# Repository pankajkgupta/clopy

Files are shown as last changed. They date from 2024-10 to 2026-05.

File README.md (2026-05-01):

# CLoPy
Closed-loop feedback training system (CLoPy) for neurofeedback and specified movement feedback in mice

This work accompanies the research paper - 
https://www.biorxiv.org/content/10.1101/2024.11.02.619716v1

For more documentation please see the Docs: https://clopy-docs.readthedocs.io/

## Folder structure
```
clopy/
│
├── 📁 analysis/                           Data analysis and visualization
│   ├── get_clmf_data.py                  Load and process CLMF behavioral data
│   ├── plot_clmf.py                      Generate CLMF figures and plots
│   └── plot_clnf.py                      Generate CLNF figures and plots
│
├── 📁 behavior/                           CLMF (Movement Feedback) Experiments
│   └── cla_dlc_trials_speed.py           Main CLMF experiment script
│
├── 📁 brain/                              CLNF (Neurofeedback) Experiments
│   ├── cla_reward_punish_1roi.py         CLNF single ROI experiment
│   └── cla_reward_punish_2roi.py         CLNF dual ROI experiment
│
├── 📁 3D-print/                           3D-printable hardware components
│   ├── MirrorHolderFront.dxf
│   ├── MirrorHolderRear.dxf
│   ├── MouseEnclosureTop.dxf
│   ├── MouseHeadFixBack.dxf
│   ├── MouseHeadFixBottom.dxf
│   ├── MouseHeadFixPost.dxf
│   └── MouseHeadFixTop.dxf
│
├── 📁 processed_data/                     Preprocessed data for figure reproduction
│   ├── clmf_kld_df.csv
│   ├── clmf_sessions_df.csv
│   ├── clmf_trials_df.csv
│   └── clnf_sessions_df.csv
│
├── 📁 docs/                               ReadTheDocs documentation
│   ├── 📁 assets/                        Images, animations, and documentation
│   │   ├── fig1.png                      System overview diagram
│   │   ├── fig2.png                      Module architecture diagram
│   │   ├── animation1_clnf.gif            Neurofeedback trial example
│   │   └── *.pdf                         Hardware assembly instructions
│   │
│   ├── mkdocs.yml                        Documentation configuration
│   ├── index.md                          Home page
│   ├── installation.md                   Installation guide
│   ├── quickstart.md                     Quick start tutorial
│   ├── clnf.md                           CLNF experiment guide
│   ├── clmf.md                           CLMF experiment guide
│   ├── configuration.md                  Configuration reference
│   ├── hardware.md                       Hardware setup guide
│   ├── analysis.md                       Data analysis guide
│   ├── troubleshooting.md                Troubleshooting & FAQ
│   ├── api.md                            API reference
│   └── requirements.txt                  Documentation dependencies
│
├── 📄 CameraFactory.py                    Camera abstraction layer
├── 📄 config.ini                          Configuration file for all experiments
├── 📄 helper.py                           Utility functions and enums
├── 📄 roi_manager.py                      ROI definition and management
├── 📄 PiCameraStream.py                   Raspberry Pi camera driver
├── 📄 SentechCameraStream.py              Sentech USB camera driver
├── 📄 VideoStream.py                      Generic video stream interface
├── 📄 README.md                           Project overview
├── 📄 .readthedocs.yaml                   ReadTheDocs configuration
└── 📄 .gitignore                          Git ignore rules
```

## Setup

Overview of CLNF process (A) and CLMF process (B)

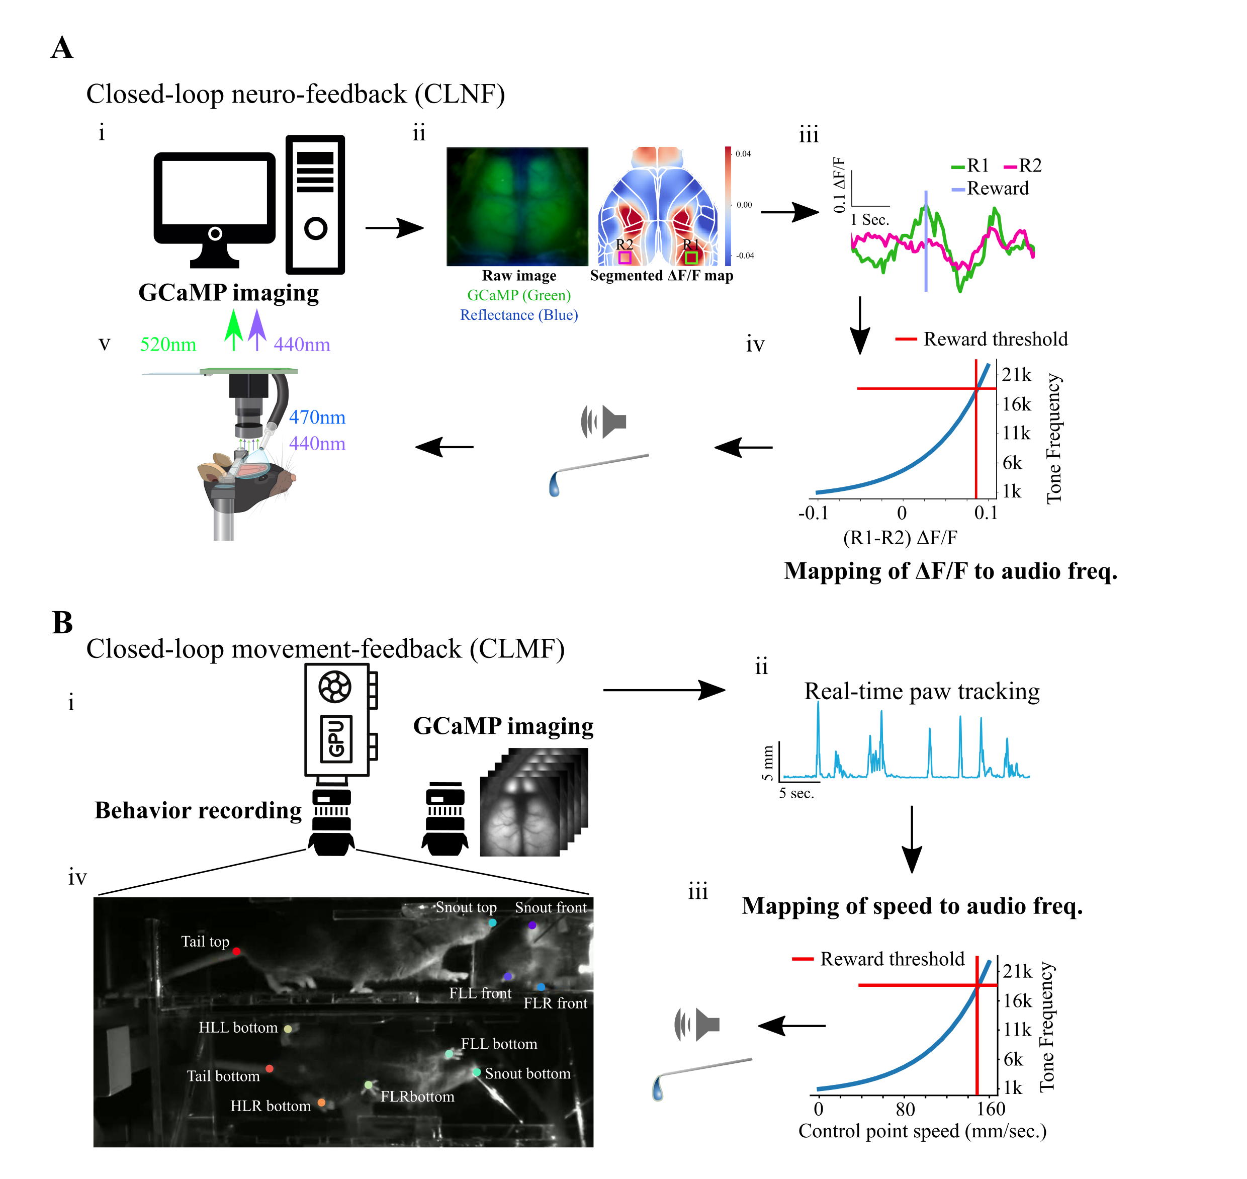
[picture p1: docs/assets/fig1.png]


## Overall modules in the system:

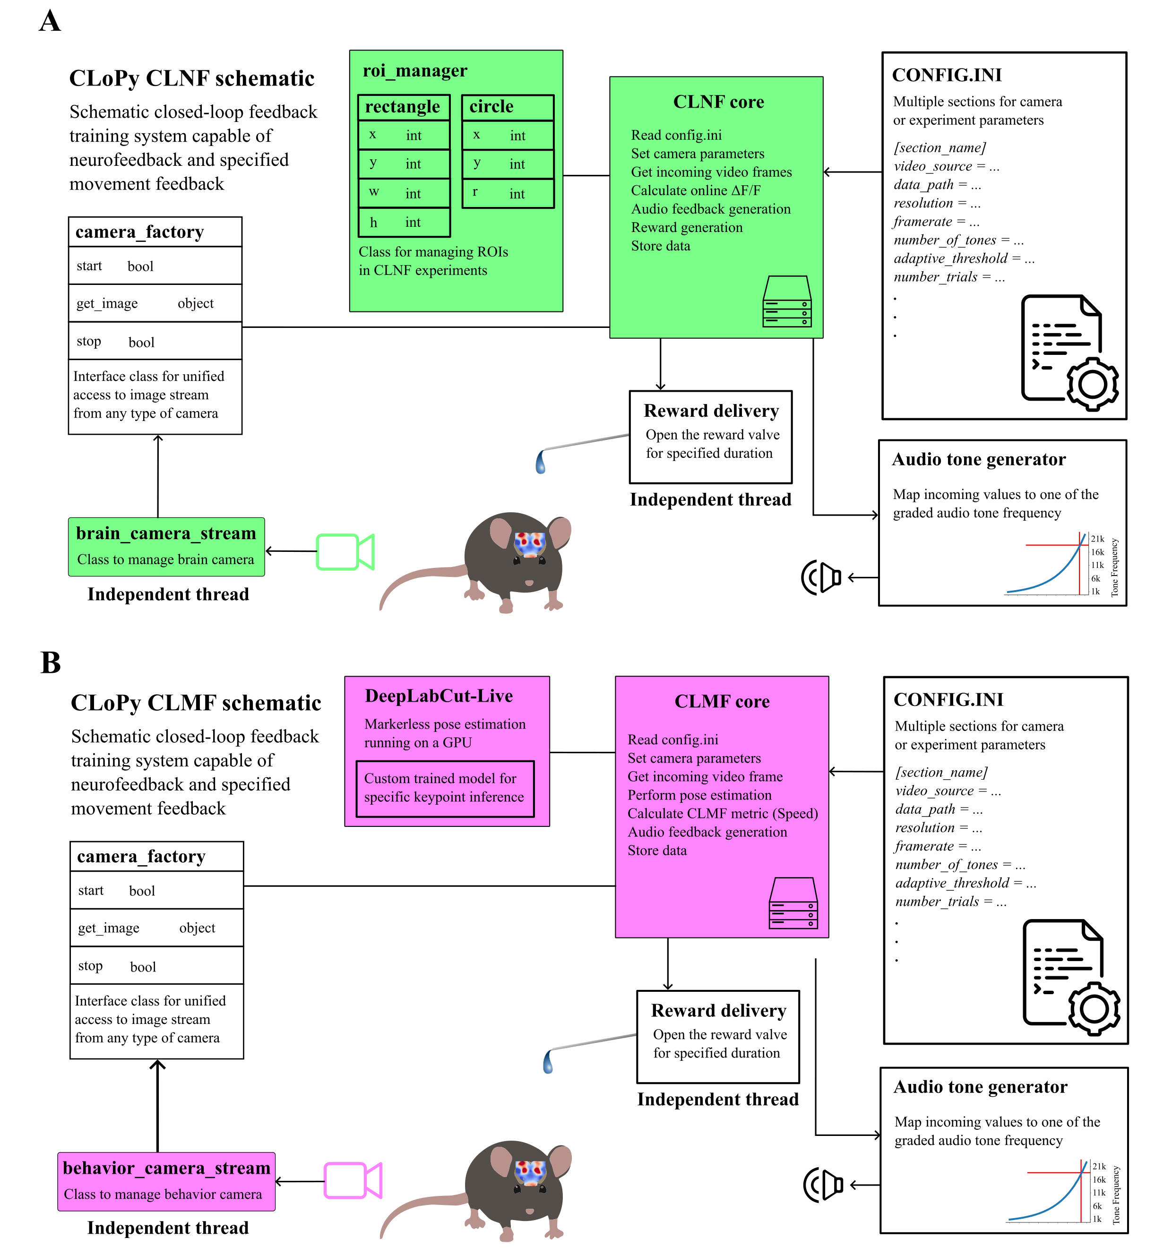
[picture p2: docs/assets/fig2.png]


## CLNF setup

> [!NOTE]
> CLNF was implemented on Raspberry Pi 4B+ and the steps below are to replicate that. 
> But the system can be adapted to other platforms with minor adaptations.

The rig hardware parts list can be found here- [CLNF_Parts_List_and_Assembly_Instructions_Gupta_et_al.pdf](https://github.com/pankajkgupta/clopy/blob/main/docs/assets/CLNF_Parts_List_and_Assembly_Instructions_Gupta_et_al.pdf)

How-to
---------------------------

Install Python >= 3.8 ([anaconda](https://docs.anaconda.com/anaconda/install/) or [miniconda](https://docs.anaconda.com/miniconda/miniconda-install/) recommended)

> [!TIP]
> We highly recommend creating a virtual environment such as using conda and installing all the Python packages in that environment

The following commands are to be run in a Terminal (Linux/MacOS)

```
conda create -n clopy
```
### Activate the conda environment

```
conda activate clopy
```

### Install dependencies
```
pip3 install opencv-python tables cvui roipoly scipy pandas joblib pillow videofig imutils gpiozero Adafruit-Blinka adafruit-circuitpython-mpr121
```

### Install [PyAudio](https://people.csail.mit.edu/hubert/pyaudio/)
Follow your platform-specific instructions. The commands below are specific to Linux-based systems

```
sudo apt-get install portaudio19-dev python3-pyaudio
```
```
pip3 install PyAudio
```

### Install [Audiostream](https://github.com/kivy/audiostream)

```
sudo apt-get install libsdl1.2-dev
```
```
sudo apt-get install libsdl-mixer1.2-dev
```
```
pip3 install cython==0.29.21
```
```
pip3 install kivy
```

### Clone the Audiostream repo:
```
git clone https://github.com/kivy/audiostream.git
```
or download as a zip and extract.

### Change the directory to the downloaded repository

```
cd audiostream
```
### Run Audiostream setup installation
```
python setup.py install
```

### After setup completes successfully, change the current directory to a directory where you want to clone CLoPy (eg. home directory)
```
cd ~
```

### Clone the CLoPy repository:

```bash
git clone https://github.com/pankajkgupta/clopy.git
```

   or download as a zip and extract.

```
cd clopy
```

### In the clopy root directory run

For CLNF experiment involving single ROI (1ROI):
```bash
python brain/cla_reward_punish_1roi.py
```
For CLNF experiment involving dual ROI (2ROI):
```bash
python brain/cla_reward_punish_2roi.py
```

... you would be prompted to enter a 'mouse_id'. After this step, you will see a 
preview window where you can make sure all settings and setup look fine 
before hitting <kbd>Esc</kbd> button the the keyboard to start a session.

If you want to interrupt the session after it starts, press the <kbd>Esc</kbd> button while the window is selected, to close the session as the program.

### Here are some reward-centered dorsal cortical maps averaged over trials of a session:

CLoPy

## CLMF setup

> [!NOTE]
> CLMF was implemented on Nvidia-Jetson Orin and steps below are to replicate that. 
> But the system can be adapted to other platforms with a GPU capable of inference.

The rig hardware parts list can be found here- [CLMF_Parts_List_and_Assembly_Instructions_Gupta_et_al.pdf](https://github.com/pankajkgupta/clopy/blob/main/docs/assets/CLMF_Parts_List_and_Assembly_Instructions_Gupta_et_al.pdf)

How-to
---------------------------

Install Python >= 3.8 ([anaconda](https://docs.anaconda.com/anaconda/install/) or [miniconda](https://docs.anaconda.com/miniconda/miniconda-install/) recommended)

> [!TIP]
> We highly recommend creating a virtual environment such as using conda and installing all the Python packages in that environment

```
conda create -n clopy
```
### Activate the conda environment

```
conda activate clopy
```

### Install dependencies
```
pip3 install opencv-python tables cvui roipoly scipy pandas joblib pillow videofig imutils
```
### Install [PyAudio](https://people.csail.mit.edu/hubert/pyaudio/)
Follow your platform-specific instructions. The commands below are specific to Linux-based systems

```
sudo apt-get install portaudio19-dev python3-pyaudio
```
```
pip3 install PyAudio
```

### Install [Audiostream](https://github.com/kivy/audiostream)

```
sudo apt-get install libsdl1.2-dev
```
```
sudo apt-get install libsdl-mixer1.2-dev
```
```
pip3 install cython==0.29.21
```
```
pip3 install kivy
```

### Clone the Audiostream repo:
```
git clone https://github.com/kivy/audiostream.git
```
or download as zip and extract.

### Change the directory to the downloaded repository

```
cd audiostream
```
### Run Audiostream setup installation
```
python setup.py install
```

### Install DeepLabCut-Live
> [!IMPORTANT]
> Please check the DeepLabCut-Live ([Kane et al, eLife 2020](https://elifesciences.org/articles/61909)) [GitHub page](https://github.com/DeepLabCut/DeepLabCut-live) for latest instructions for installing this package. 
> Please also check the tensorflow version requirements on their GitHub page. 
> 
> If all dependencies are fine, the command below usually works fine

```
pip install deeplabcut-live
```

### After setup completes successfully, change the current directory to a directory where you want to clone CLoPy (eg. home directory)
```
cd ~
```

### Clone the CLoPy repository:

```bash
git clone https://github.com/pankajkgupta/clopy.git
```

   or download as zip and extract.

```
cd clopy
```

### In the clopy root directory run

```bash
python behavior/cla_dlc_trials_speed.py
```

... you would be prompted to enter a 'mouse_id'. After this step, you will see a 
preview window where you can make sure all settings and setup look fine 
before hitting <kbd>Esc</kbd> button the the keyboard to start a session.

If you want to interrupt the session after it starts, press the <kbd>Esc</kbd> button while the window is selected, to close the session as the program.

### Here are two example trials from the CLMF experiment where the task was to move the left fore-limb (top animation)

CLoPy

### ... and later the same mouse was trained to move the right fore-limb

CLoPy

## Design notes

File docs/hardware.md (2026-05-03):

# Hardware Setup

Detailed hardware assembly instructions for CLoPy experiments.

!!! info "Parts List"
    Complete parts lists are available in the PDF: [CLNF_Parts_List_and_Assembly_Instructions_Gupta_et_al.pdf](https://github.com/pankajkgupta/clopy/blob/main/assets/CLNF_Parts_List_and_Assembly_Instructions_Gupta_et_al.pdf)

## CLNF Hardware (Raspberry Pi)

### Components

| Component | Quantity | Notes |
|---|---|---|
| Raspberry Pi 4B+ | 1 | |
| Raspberry Pi Camera v2 | 1 | |
| MPR121 Capacitive Touch | 1 | Lick detection |
| LEDs (various) | 4 | Behavior, Reward, Fail, TTL |
| Water valve | 1 | Reward delivery |
| Speaker | 1 | Audio feedback |
| Power supply | 1 | 5V 3A minimum |

### Pin Connections

#### GPIO Pinout (Board numbering)

```
┌─────────────────────────────────────────────┐
│              Raspberry Pi GPIO              │
├─────────────────────────────────────────────┤
│                                             │
│  3.3V  ──── VCC (MPR121)                    │
│  GND   ──── GND (MPR121, LEDs)              │
│  SCL   ──── SCL (MPR121)                    │
│  SDA   ──── SDA (MPR121)                    │
│                                             │
│  GPIO17 ──── Behavior LED (pin 1)           │
│  GPIO27 ──── Reward LED (pin 1)             │
│  GPIO12 ──── Fail LED (pin 1)               │
│  GPIO21 ──── Light TTL (pin 1)              │
│                                             │
└─────────────────────────────────────────────┘
```

#### LED Wiring

```
GPIO ──── Resistor (330Ω) ──── LED ──── GND
```

#### Water Valve

Connect to relay controlled by Arduino or GPIO.

### Camera Setup

1. Connect camera to CSI port
2. Enable camera in `raspi-config`:
   ```bash
   sudo raspi-config
   ```
   → Interface Options → Camera → Enable

3. Test camera:
   ```bash
   raspistill -o test.jpg
   ```

### I2C Setup for MPR121

1. Enable I2C:
   ```bash
   sudo raspi-config
   ```
   → Interface Options → I2C → Enable

2. Install tools:
   ```bash
   sudo apt-get install i2c-tools
   ```

3. Verify connection:
   ```bash
   sudo i2cdetect -y 1
   ```
   Should show device at address `0x5a`

## CLMF Hardware (Jetson Orin)

### Components

| Component | Quantity | Notes |
|---|---|---|
| Nvidia Jetson Orin | 1 | |
| Sentech Camera | 1 | USB3 preferred |
| Arduino Uno/Mega | 1 | TTL and LED control |
| Water valve | 1 | Reward delivery |
| Speaker | 1 | Audio feedback |

### Arduino Connections

#### Pinout

```
┌─────────────────────────────────────────────┐
│                 Arduino                     │
├─────────────────────────────────────────────┤
│                                             │
│  13  ──── Brain TTL (output)                │
│  7   ──── Reward LED                        │
│  12  ──── Fail LED                          │
│  40  ──── Light TTL                         │
│                                             │
│  GND  ──── GND (LEDs, TTL)                  │
│                                             │
│  Serial: /dev/ttyACM0                       │
│                                             │
└─────────────────────────────────────────────┘
```

#### Python Serial Configuration

```python
board = Arduino("115200", port="/dev/ttyACM0")
```

!!! note "Serial Port"
    The serial port may vary. Check with:
    ```bash
    ls /dev/ttyACM*
    ```

### Camera Setup (Sentech)

1. Connect via USB3
2. Verify:
   ```bash
   v4l2-ctl --list-devices
   ```

3. Test capture:
   ```bash
   gst-launch-1.0 v4l2src ! videoconvert ! ximagesink
   ```

### GPIO (Jetson)

Using RPi.GPIO library for compatibility:

```python
import RPi.GPIO as GPIO

GPIO.setmode(GPIO.BOARD)
GPIO.setup(pin, GPIO.OUT, initial=GPIO.LOW)
```

## Optical Setup

### Microscopy Configuration

```
                    ┌──────────────┐
                    │   LED Array  │
                    │  (470nm for  │
                    │   GCaMP6f)   │
                    └──────┬───────┘
                           │
                           ▼
              ┌────────────────────────┐
              │    Filter Set          │
              │  (Excitation/Emission) │
              └───────────┬────────────┘
                          │
                          ▼
              ┌────────────────────────┐
              │    Camera              │
              │  (Pi Camera / Sentech) │
              └────────────────────────┘
```

### Illumination

- **CLNF**: 470nm LED for GCaMP6f excitation
- Use appropriate filter sets for fluorescence imaging

### Calibration

1. **ppmm (Pixels per mm)**:
   - Image a ruler at your optical magnification
   - Count pixels across known distance
   - Set in config: `ppmm = <count>`

2. **Bregma Location**:
   - Image the skull landmarks
   - Note the (row, col) coordinates
   - Set in config: `bregma = <row>, <col>`

## Mouse Headfixing

### Setup

1. Headfix the mouse using the 3D-printed parts:
   - `MouseHeadFixTop.dxf`
   - `MouseHeadFixBottom.dxf`
   - `MouseHeadFixPost.dxf`

2. Position under camera with:
   - Cortex visible
   - Bregma identifiable
   - Target region in field of view

### ROI Placement

1. During preview, drag ROIs to:
   - Target brain region
   - Reference region (for dual ROI)

2. Positions are saved to `config.ini` after preview

## Audio Setup

### Speaker Requirements

- Frequency response: 1-24 kHz
- Small form factor for setup near mouse

### Audiostream Configuration

```python
from audiostream import get_output
from audiostream.sources.wave import SineSource

austream = get_output(channels=1, rate=44100, buffersize=128)
sinsource = SineSource(austream, 1000)
sinsource.start()
```

## Power Considerations

### Raspberry Pi

- Recommended: 5V 3A power supply
- Can power LEDs directly (with resistors)
- Water valve may need external power

### Jetson Orin

- Use official power supply
- Ensure adequate cooling
- Monitor power consumption for GPU work

## Safety Notes

!!! warning
- Always use appropriate resistors for LEDs
- Verify polarity before connecting
- Keep water valve wiring separate from logic
- Ensure proper grounding

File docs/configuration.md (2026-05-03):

# Configuration Reference

Complete reference for all configuration options in `config.ini`.

## File Structure

```ini
[configsection]
config = section_name

[section_name]
# Camera settings
# Processing settings
# Trial settings
# Reward settings
```

## CLNF Configuration Sections

### raspicambrain_reward_punish_1roi

Single ROI configuration for CLNF experiments.

```ini
[raspicambrain_reward_punish_1roi]
vid_source = PiCameraStream
data_root = /media/pi/data/cl_brain/
raw_image_file = image_stream.hdf5
resolution = 256, 256
framerate = 15
awb_mode = off
shutter_speed = 60000
iso = 800
sensor_mode = 7
dff_history = 6
ppmm = 25.6
bregma = 135, 128
seeds_mm = {"ALM": {"ML": 1.5, "AP": 2.5}, ...}
roi = M1_L
roi_size = 0.3, 0.3
audio = 1
n_tones = 18
audio_delay = 0
reward_delay = 1
reward_threshold = 0.075
adaptive_threshold = 1
total_trials = 60
max_trial_dur = 30
success_rest_dur = 10
fail_rest_dur = 15
initial_rest_dur = 30
summary_file = expt_1roi_trial_summary.csv
summary_header = mouse_id, session, data_path, start, end, duration, fps, dff_history, n_tones, reward_threshold, rewards, audio, session_type
```

### raspicambrain_reward_punish_2roi

Dual ROI configuration for CLNF experiments.

```ini
[raspicambrain_reward_punish_2roi]
vid_source = PiCameraStream
data_root = /media/pi/data/cl_brain/
raw_image_file = image_stream.hdf5
resolution = 256, 256
framerate = 15
awb_mode = off
shutter_speed = 60000
iso = 800
sensor_mode = 7
dff_history = 6
ppmm = 25.6
bregma = 135, 128
seeds_mm = {"ALM": {"ML": 1.5, "AP": 2.5}, ...}
roi_operation = BC_L-BC_R
roi_size = 0.3, 0.3
audio = 1
n_tones = 18
audio_delay = 0
reward_delay = 1
reward_threshold = 0.1
adaptive_threshold = 0
total_trials = 60
max_trial_dur = 30
success_rest_dur = 5
fail_rest_dur = 10
initial_rest_dur = 30
summary_file = expt_2roi_trial_summary.csv
summary_header = mouse_id, session, data_path, start, end, duration, fps, dff_history, n_tones, reward_threshold, rewards, audio, session_type
```

## CLMF Configuration Sections

### sentech_dlclive

Configuration for CLMF experiments with DeepLabCut-Live.

```ini
[sentech_dlclive]
vid_source = SentechCameraStream
data_root = /media/murphy/fast_storage/data/
video_file = behavior_video.mp4
resolution = 640, 320
framerate = 30
awb_mode = off
shutter_speed = 60000
iso = 800
joint_history_sec = 5
ppmm = 3.5
bregma = 108, 128
control_point = fl_l
start_center = 590,110
start_radius_mm = 4
target_center = 590,80
target_radius_mm = 6
speed_threshold = 20
audio = 1
n_tones = 18
audio_delay = 0
reward_delay = 1
reward_threshold_mm = 5
adaptive_threshold = 0
total_trials = 10
max_trial_dur = 30
success_rest_dur = 10
fail_rest_dur = 10
initial_rest_dur = 30
dlc_model_path = /path/to/dlc-model/
summary_file = expt_dlclive_summary.csv
summary_header = mouse_id, session, data_path, start, end, duration, fps, n_tones, start_radius, target_radius, rewards, audio, session_type
```

## Parameter Descriptions

### Camera Settings

| Parameter | Description | Example |
|---|---|---|
| `vid_source` | Camera driver class | `PiCameraStream`, `SentechCameraStream` |
| `resolution` | Image width, height | `256, 256` or `640, 320` |
| `framerate` | Frames per second | `15`, `30`, `60` |
| `awb_mode` | Auto white balance | `off`, `auto` |
| `shutter_speed` | Camera shutter speed (μs) | `60000`, `600000` |
| `iso` | Camera ISO | `800` |
| `sensor_mode` | PiCamera sensor mode | `7` |

### Processing Settings

| Parameter | Description | Example |
|---|---|---|
| `dff_history` | Frames for baseline calculation | `6` |
| `ppmm` | Pixels per millimeter | `25.6`, `3.5` |
| `bregma` | Bregma landmark (row, col) | `135, 128` |
| `seeds_mm` | Brain region coordinates (JSON) | `{"ALM": {"ML": 1.5, "AP": 2.5}}` |

### ROI Settings

| Parameter | Description | Example |
|---|---|---|
| `roi` | Single ROI name | `M1_L` |
| `roi_operation` | Dual ROI operation | `BC_L-BC_R`, `M1_L+ALM` |
| `roi_size` | ROI size in mm | `0.3, 0.3` |
| `start_center` | Start ROI center (pixels) | `590, 110` |
| `start_radius_mm` | Start ROI radius (mm) | `4` |
| `target_center` | Target ROI center (pixels) | `590, 80` |
| `target_radius_mm` | Target ROI radius (mm) | `6` |

### Audio Settings

| Parameter | Description | Example |
|---|---|---|
| `audio` | Enable audio feedback | `0` or `1` |
| `n_tones` | Number of frequency bins | `18` |
| `audio_delay` | Audio delay (frames) | `0` |

### Reward Settings

| Parameter | Description | Example |
|---|---|---|
| `reward_threshold` | ΔF/F threshold (CLNF) | `0.075` |
| `reward_threshold_mm` | Distance threshold (CLMF) | `5` |
| `speed_threshold` | Speed threshold (CLMF) | `20` |
| `reward_delay` | Reward delay (frames) | `1` |
| `adaptive_threshold` | Enable adaptive threshold | `0` or `1` |

### Trial Settings

| Parameter | Description | Example |
|---|---|---|
| `total_trials` | Number of trials | `60` |
| `max_trial_dur` | Max trial duration (sec) | `30` |
| `success_rest_dur` | Rest after success (sec) | `10` |
| `fail_rest_dur` | Rest after failure (sec) | `15` |
| `initial_rest_dur` | Initial rest period (sec) | `30` |

### DeepLabCut Settings (CLMF)

| Parameter | Description | Example |
|---|---|---|
| `dlc_model_path` | Path to DLC model | `/path/to/model/` |
| `control_point` | Body part to track | `fl_l` |
| `joint_history_sec` | Stability history (sec) | `5` |

### Data Output Settings

| Parameter | Description | Example |
|---|---|---|
| `data_root` | Base data directory | `/media/pi/data/` |
| `raw_image_file` | HDF5 file name | `image_stream.hdf5` |
| `video_file` | Video file name | `behavior_video.mp4` |
| `summary_file` | Summary CSV name | `expt_summary.csv` |
| `summary_header` | CSV column names | (comma-separated) |

## Brain Region Coordinates

Default seed positions (in mm from bregma):

| Region | ML | AP |
|---|----|----|
| ALM | 1.5 | 2.5 |
| M1 | 1.86 | 0.64 |
| M2 | 0.87 | 1.42 |
| FL | 2.45 | -0.57 |
| HL | 1.69 | -1.15 |
| BC | 3.46 | -1.73 |
| V1 | 2.52 | -3.77 |
| RS | 0.62 | -2.89 |

## Editing Configuration

1. Open `config.ini` in a text editor
2. Find the appropriate section
3. Modify values as needed
4. Save the file

!!! tip "ROI Position Adjustment"
    After running the preview, ROI positions are saved back to `config.ini`. You can also manually specify coordinates:

        m1_l = 76,114,8,8

    Format: `x, y, width, height`

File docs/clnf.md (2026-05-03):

# CLNF - Closed-Loop Neurofeedback

CLNF uses real-time calcium imaging (ΔF/F) to provide audio feedback correlated with neural activity in a target brain region.

## How It Works

```
Camera → ΔF/F Calculation → Threshold Check → Audio Feedback + Reward
```

1. **Imaging**: Wide-field calcium imaging of cortical activity
2. **Processing**: Calculate ΔF/F (delta F over F) in real-time
3. **Feedback**: Map activity level to audio tone frequency
4. **Reward**: Deliver water when activity exceeds threshold

## Running CLNF Experiments

### Single ROI Experiment

```bash
python brain/cla_reward_punish_1roi.py
```

Monitors a single brain region. Reward triggered when activity exceeds threshold.

### Dual ROI Experiment

```bash
python brain/cla_reward_punish_2roi.py
```

Monitors two brain regions (can be extended to more number of regions) with mathematical operations such as:

- **Addition**: `ROI1 + ROI2`
- **Subtraction**: `ROI1 - ROI2`

Other operations such as multiplication, division etc. are supported and can be specified in the `config.ini` file.

## Configuration Parameters

### Required Settings (config.ini)

```ini
[raspicambrain_reward_punish_1roi]
vid_source = PiCameraStream
data_root = /path/to/data/
resolution = 256, 256
framerate = 15
dff_history = 6
ppmm = 25.6
bregma = 135, 128
roi = M1_L
roi_size = 0.3, 0.3
audio = 1
n_tones = 18
reward_threshold = 0.075
adaptive_threshold = 1
total_trials = 60
max_trial_dur = 30
success_rest_dur = 10
fail_rest_dur = 15
initial_rest_dur = 30
```

### Parameter Reference

| Parameter | Description | Typical Value |
|---|---|---|
| `vid_source` | Camera driver | `PiCameraStream` |
| `resolution` | Image resolution | `256, 256` |
| `framerate` | Acquisition frame rate | `15` |
| `dff_history` | Frames for baseline (seconds × framerate) | `6` (0.4s) |
| `ppmm` | Pixels per millimeter | `25.6` |
| `bregma` | Bregma landmark position | `135, 128` |
| `roi` | Target brain region | `M1_L`, `ALM`, etc. |
| `roi_size` | ROI dimensions (mm) | `0.3, 0.3` |
| `n_tones` | Number of audio frequencies | `18` |
| `reward_threshold` | ΔF/F threshold for reward | `0.075` |
| `adaptive_threshold` | Auto-adjust threshold | `0` or `1` |
| `total_trials` | Number of trials per session | `60` |
| `max_trial_dur` | Maximum trial duration (sec) | `30` |
| `success_rest_dur` | Rest after success (sec) | `10` |
| `fail_rest_dur` | Rest after failure (sec) | `15` |
| `initial_rest_dur` | Initial rest before first trial | `30` |

## Available Brain Regions

Pre-configured seed locations (in mm from bregma):

```python
seeds_mm = {
    "ALM": {"ML": 1.5, "AP": 2.5},
    "M1": {"ML": 1.8603, "AP": 0.64181},
    "M2": {"ML": 0.87002, "AP": 1.4205},
    "FL": {"ML": 2.4526, "AP": -0.5668},
    "HL": {"ML": 1.6942, "AP": -1.1457},
    "BC": {"ML": 3.4569, "AP": -1.727},
    "V1": {"ML": 2.5168, "AP": -3.7678},
    "RS": {"ML": 0.62043, "AP": -2.8858},
    # ... and more
}
```

## Audio Feedback Mapping

Neural activity is mapped to audio frequency:

```
ΔF/F = 0    →  1000 Hz (low tone)
ΔF/F = threshold → 1000 × 2^(n_tones/4) Hz (high tone)
```

The system uses quarter-octave frequency increments from 1-24 kHz.

## Session Types

Configure reward behavior in code:

```python
# Normal audio + normal reward
sessionType = clh.SessionType.normal_audio_normal_reward

# No audio + random reward (control)
sessionType = clh.SessionType.no_audio_random_reward
```

## Adaptive Thresholding

When `adaptive_threshold = 1`:

- Every 30 seconds, check rewards in epoch
- If > 1 reward: increase threshold by 0.002
- If 0 rewards: decrease threshold by 0.002

This maintains consistent reward rates across sessions.

## Hardware Setup

### Required Components

- Raspberry Pi 4B+
- Raspberry Pi Camera (v2)
- MPR121 capacitive touch sensor (lick detection)
- LED array (behavior, reward, fail indicators)
- Water reward valve
- Audio speaker

### GPIO Pinout

| GPIO | Function |
|---|---|
| 17 | Behavior LED |
| 27 | Reward LED |
| 12 | Fail LED |
| 21 | Light TTL |

### I2C Connections

- MPR121 on I2C bus (SCL/SDA)

## Data Output

### VideoTimestamp.txt Format

```
frame	time	roi_dff	freq	rew_threshold	reward	trial	audio	lick
```

### Summary CSV

```
mouse_id, session, data_path, start, end, duration, fps, dff_history, n_tones, reward_threshold, rewards, audio, session_type
```

## Example Workflow

1. Edit `config.ini` with your parameters
2. Run: `python brain/cla_reward_punish_1roi.py`
3. Enter mouse ID when prompted
4. Adjust ROI positions in preview window
5. Press `Esc` to start session
6. Monitor real-time feedback
7. Press `Esc` to end or wait for completion

## Troubleshooting

See [Troubleshooting Guide](troubleshooting.md) for common issues.

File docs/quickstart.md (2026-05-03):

# Quick Start Guide

Get up and running with CLoPy in minutes.

## Running Your First Experiment

### CLNF Experiment (Single ROI)

```bash
cd clopy
python brain/cla_reward_punish_1roi.py
```

### CLNF Experiment (Dual ROI)

```bash
cd clopy
python brain/cla_reward_punish_2roi.py
```

### CLMF Experiment

```bash
cd clopy
python behavior/cla_dlc_trials_speed.py
```

## What Happens Next

1. **Mouse ID Prompt**: Enter your mouse identifier
   ```
   Please enter mouse ID: M001
   ```

2. **Preview Window**: A preview window appears showing:

    - Live camera feed
    - ROI positions (draggable rectangles)
    - DFF (ΔF/F) visualization
    - Luminosity sparklines

3. **Verify Setup**: Ensure:

    - Camera is properly positioned
    - ROI covers the target brain region
    - Bregma landmark is visible
    - Lighting is adequate

4. **Start Session**: Press `Esc` to begin the experiment

5. **During Experiment**:

    - Trials start automatically after initial rest period
    - Audio tones play during active trials
    - Green LED flashes on successful trials
    - Red LED flashes on failed trials

6. **End Session**: Press `Esc` to stop early, or let it complete

## Understanding the Trial Flow

```
┌─────────────────────────────────────────────────────────────┐
│                      Trial Structure                        │
├─────────────────────────────────────────────────────────────┤
│                                                             │
│  ┌──────────┐    ┌──────────────┐     ┌────────────┐        │
│  │  Rest    │───▶│    Trial     │───▶│  Outcome   │        │
│  │ Period   │    │   (max 30s)  │     │            │        │
│  └──────────┘    └──────────────┘     └────────────┘        │
│  10-15 seconds                             │                │
│                                            ▼                │
│                                    ┌───────┴───────┐        │
│                                    │               │        │
│                                Success            Fail      │
│                                (reward)         (buzzer)    │
│                                   │                │        │
│                                   ▼                ▼        │
│                                10s rest        15s rest     │
│                                                             │
└─────────────────────────────────────────────────────────────┘
```

## Key Controls

| Key | Action |
|-----|---|
| `Esc` | Start/Stop experiment |
| Mouse Drag | Move ROI positions |
| `Esc` (during trial) | Abort session |

## Data Output

After each session, data is saved to:

```
data_root/mouse_id/YYYYMMDDHHMMSS/
├── config.ini              # Session configuration
├── image_stream.hdf5       # Raw imaging data (CLNF)
├── video.mp4               # Behavior video (CLMF)
└── VideoTimestamp.txt      # Trial-by-trial log
```

## Configuration First

Before running experiments, you'll need to configure:

1. **Camera settings** in `config.ini`
2. **ROI positions** (brain regions)
3. **Reward thresholds**
4. **Trial parameters**

See [Configuration Guide](configuration.md) for details.

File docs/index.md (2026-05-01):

# CLoPy - Closed-Loop Feedback Training System

CLoPy is a closed-loop feedback training system for neurofeedback and specified movement feedback in mice. This system enables real-time manipulation of neural activity or behavior based on calcium imaging or pose estimation.

!!! info "Paper"
    This work accompanies the research paper: [https://elifesciences.org/reviewed-preprints/105070](https://elifesciences.org/reviewed-preprints/105070)

## Overview

CLoPy implements two complementary closed-loop paradigms:

| Feature | CLNF | CLMF |
|---|---|---|
| **Full Name** | Closed-Loop Neurofeedback | Closed-Loop Movement Feedback |
| **Input** | Calcium imaging (Gcamp6f) | DeepLabCut pose estimation |
| **Platform** | Raspberry Pi 4B+ | Nvidia Jetson Orin |
| **Feedback** | Audio tones mapped to neural activity | Audio tones mapped to movement speed |
| **Reward** | Water reward on threshold crossing | Water reward on target movement |

## System Architecture

CLoPy platform

## Key Features

- **Real-time Processing**: Sub-second latency for feedback delivery
- **Adaptive Thresholding**: Automatically adjusts reward thresholds based on performance
- **Multiple ROI Support**: Single ROI (1ROI) or dual ROI (2ROI) experiments
- **Audio Feedback**: Sonification of neural activity or movement speed using variable frequency tones
- **Trial-based Structure**: Well-defined trials with rest periods and success/fail outcomes
- **Data Logging**: Comprehensive logging of all parameters and events

## Folder Structure

```
clopy/
│
├── 📁 analysis/                           Data analysis and visualization
│   ├── get_clmf_data.py                  Load and process CLMF behavioral data
│   ├── plot_clmf.py                      Generate CLMF figures and plots
│   └── plot_clnf.py                      Generate CLNF figures and plots
│
├── 📁 behavior/                           CLMF (Movement Feedback) Experiments
│   └── cla_dlc_trials_speed.py           Main CLMF experiment script
│
├── 📁 brain/                              CLNF (Neurofeedback) Experiments
│   ├── cla_reward_punish_1roi.py         CLNF single ROI experiment
│   └── cla_reward_punish_2roi.py         CLNF dual ROI experiment
│
├── 📁 3D-print/                           3D-printable hardware components
│   ├── MirrorHolderFront.dxf
│   ├── MirrorHolderRear.dxf
│   ├── MouseEnclosureTop.dxf
│   ├── MouseHeadFixBack.dxf
│   ├── MouseHeadFixBottom.dxf
│   ├── MouseHeadFixPost.dxf
│   └── MouseHeadFixTop.dxf
│
├── 📁 processed_data/                     Preprocessed data for figure reproduction
│   ├── clmf_kld_df.csv
│   ├── clmf_sessions_df.csv
│   ├── clmf_trials_df.csv
│   └── clnf_sessions_df.csv
│
├── 📁 docs/                               ReadTheDocs documentation
│   ├── 📁 assets/                        Images, animations, and documentation
│   │   ├── fig1.png                      System overview diagram
│   │   ├── fig2.png                      Module architecture diagram
│   │   ├── animation1_clnf.gif            Neurofeedback trial example
│   │   └── *.pdf                         Hardware assembly instructions
│   │
│   ├── mkdocs.yml                        Documentation configuration
│   ├── index.md                          Home page
│   ├── installation.md                   Installation guide
│   ├── quickstart.md                     Quick start tutorial
│   ├── clnf.md                           CLNF experiment guide
│   ├── clmf.md                           CLMF experiment guide
│   ├── configuration.md                  Configuration reference
│   ├── hardware.md                       Hardware setup guide
│   ├── analysis.md                       Data analysis guide
│   ├── troubleshooting.md                Troubleshooting & FAQ
│   ├── api.md                            API reference
│   └── requirements.txt                  Documentation dependencies
│
├── 📄 CameraFactory.py                    Camera abstraction layer
├── 📄 config.ini                          Configuration file for all experiments
├── 📄 helper.py                           Utility functions and enums
├── 📄 roi_manager.py                      ROI definition and management
├── 📄 PiCameraStream.py                   Raspberry Pi camera driver
├── 📄 SentechCameraStream.py              Sentech USB camera driver
├── 📄 VideoStream.py                      Generic video stream interface
├── 📄 README.md                           Project overview
├── 📄 .readthedocs.yaml                   ReadTheDocs configuration
└── 📄 .gitignore                          Git ignore rules
```

### Directory Descriptions

| Directory | Purpose |
|---|---|
| `analysis/` | Scripts for data analysis and figure generation |
| `behavior/` | CLMF experiment scripts (Jetson Orin) |
| `brain/` | CLNF experiment scripts (Raspberry Pi) |
| `3D-print/` | 3D-printable hardware components (DXF format) |
| `processed_data/` | Pre-processed data for recreating paper figures |
| `docs/` | ReadTheDocs documentation source files and assets |
| `docs/assets/` | Images, animations, and visual files |

## Quick Links

- [Installation Guide](installation.md)
- [CLNF Experiment Setup](clnf.md)
- [CLMF Experiment Setup](clmf.md)
- [Configuration Reference](configuration.md)
- [Hardware Assembly](hardware.md)
- [Troubleshooting](troubleshooting.md)

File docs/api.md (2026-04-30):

# API Reference

Detailed API documentation for CLoPy modules and classes.

## Core Modules

### CameraFactory

Factory class for creating camera instances.

```python
from CameraFactory import CameraFactory
```

#### Methods

##### `CameraFactory(camera_instance)`

Create a camera wrapper.

**Parameters:**
- `camera_instance`: Camera object from camera driver

**Returns:** Wrapped camera object

**Example:**
```python
from PiCameraStream import PiCameraStream
vs = CameraFactory(PiCameraStream(cfgDict).start())
```

---

### roi_manager

ROI management for defining and manipulating regions of interest.

#### Classes

##### `Rect`

Rectangle ROI class.

```python
from roi_manager import Rect
```

**Attributes:**
- `x`, `y`: Top-left corner coordinates
- `w`, `h`: Width and height
- `name`: ROI identifier
- `color`: BGR color tuple
- `avgDff`: Current ΔF/F value

**Methods:**

```python
roi = Rect('M1_L', x=100, y=100, w=20, h=20, color=[0, 0, 255])
area = roi.area()  # Returns w * h
```

##### `Circle`

Circular ROI class.

```python
from roi_manager import Circle
```

**Attributes:**
- `x`, `y`: Center coordinates
- `r`: Radius
- `name`: ROI identifier
- `color`: BGR color tuple

**Methods:**

```python
roi = Circle('start', x=100, y=100, r=30, color=[0, 200, 0])
area = roi.area()  # Returns π * r²
```

##### `annots`

Annotation container class.

```python
from roi_manager import annots
```

**Attributes:**
- `rois`: Dictionary of ROI objects
- `image`: Current frame
- `frame_n`: Frame number
- `wname`: Window name

---

### helper

Utility functions for CLoPy.

```python
import helper as clh
```

#### Functions

##### `GetConfigValues(data_dir)`

Load configuration from session directory.

```python
cfgDict = clh.GetConfigValues('/path/to/session/')
```

**Parameters:**
- `data_dir`: Path to session directory

**Returns:** Dictionary of configuration values

##### `generate_seeds(bregma, seeds_mm, ppmm, side)`

Generate pixel coordinates for brain regions.

```python
br = clh.Position(135, 128)  # bregma position
seeds = clh.generate_seeds(br, seeds_mm, ppmm, 'u')
```

**Parameters:**
- `bregma`: Position object with row, col
- `seeds_mm`: Dictionary of region coordinates in mm
- `ppmm`: Pixels per millimeter
- `side`: Side indicator ('u' for unilateral)

**Returns:** Dictionary of pixel coordinates

##### `get_freqs(n_tones)`

Generate frequency values for audio feedback.

```python
freqs = clh.get_freqs(18)
```

**Parameters:**
- `n_tones`: Number of frequency bins

**Returns:** Dictionary mapping bin indices to frequencies

#### Enums

##### `SessionType`

Experiment session types.

```python
from helper import SessionType

sessionType = SessionType.normal_audio_normal_reward
```

**Values:**
- `normal_audio_normal_reward`: Standard feedback and rewards
- `single_audio_normal_reward`: Constant tone with rewards
- `no_audio_random_reward`: No feedback, random rewards (control)
- `normal_audio_no_reward`: Feedback only, no rewards
- `no_audio_no_reward`: No feedback, no rewards (control)

---

### configparser

Configuration file handling.

```python
from configparser import ConfigParser
```

**Usage:**

```python
config = ConfigParser()
config.read('config.ini')

# Read values
value = config.get('section', 'key')
value = config.getint('section', 'key')
value = config.getfloat('section', 'key')
value = config.getboolean('section', 'key')

# Write values
config.set('section', 'key', 'value')

# Save
with open('config.ini', 'w') as f:
    config.write(f)
```

---

## CLNF Modules

### cla_reward_punish_1roi

Single ROI closed-loop neurofeedback experiment.

```bash
python brain/cla_reward_punish_1roi.py
```

#### Key Variables

| Variable | Type | Description |
|---|---|---|
| `rois` | list | List of Rect objects |
| `runningImgQuROI` | list | Deques for DFF history |
| `relAvgDff` | float | Current ΔF/F value |
| `reward_threshold` | float | Threshold for reward |
| `dff_bins` | ndarray | DFF to frequency mapping |

#### Trial Flow

1. Rest period (configurable duration)
2. Trial starts → audio plays
3. Monitor ΔF/F in ROI
4. If ΔF/F > threshold → reward + success LED
5. If timeout → failure LED
6. Rest period (varies by outcome)

---

### cla_reward_punish_2roi

Dual ROI closed-loop neurofeedback experiment.

```bash
python brain/cla_reward_punish_2roi.py
```

#### Key Differences from 1ROI

- Uses `roi_operation` for mathematical combination
- Tracks two ROIs
- Calculates: `ROI1 + ROI2` or `ROI1 - ROI2`

**Example:**
```python
roi_operation = 'BC_L-BC_R'  # Left - Right barrel cortex
relAvgDff = rois[0].avgDff - rois[1].avgDff
```

---

## CLMF Modules

### cla_dlc_trials_speed

Closed-loop movement feedback experiment.

```bash
python behavior/cla_dlc_trials_speed.py
```

#### Key Variables

| Variable | Type | Description |
|---|---|---|
| `pose` | ndarray | Current pose estimates |
| `cj_speed` | float | Control joint speed |
| `speed_threshold` | int | Speed threshold for reward |
| `control_point_ix` | int | Index of tracked body part |
| `start_roi_manager` | Circle | Start region |
| `target_roi_manager` | Circle | Target region |

#### DeepLabCut-Live Integration

```python
from dlclive import DLCLive, Processor

# Initialize
dlc_proc = Processor()
dlc_live = DLCLive(model_path, processor=dlc_proc, display=False)

# Get pose
pose = dlc_live.get_pose(image)

# Access specific body part
x, y = pose[control_point_ix][0:2]
```

#### Trial Initialization Options

Three modes for starting trials (see code comments):

1. **Stability-based** (default): Paw must be stationary
2. **Start ROI-based**: Paw must be in start circle
3. **Immediate**: Trial starts after rest period

---

## Data Structures

### VideoTimestamp.txt (CLNF)

Tab-separated log file:

```
frame	time	roi_dff	freq	rew_threshold	reward	trial	audio	lick
```

| Column | Type | Description |
|---|---|---|
| frame | int | Frame number |
| time | str | Timestamp (YYYY-MM-DD HH:MM:SS.ffffff) |
| roi_dff | float | ΔF/F value |
| freq | int | Audio frequency (Hz) |
| rew_threshold | float | Current threshold |
| reward | int | -1=fail, 0=none, 1=success |
| trial | int | Trial number |
| audio | int | 0=no audio, 1=audio playing |
| lick | int | 0=no lick, 1=lick detected |

### VideoTimestamp.txt (CLMF)

Tab-separated log file:

```
frame	time	cj_speed	freq	reward	trial	audio	lick	pose_x	pose_y	likelihood...
```

| Column | Type | Description |
|---|---|---|
| cj_speed | float | Control joint speed (pixels/frame) |
| pose_* | float | x, y, likelihood for each body part |

### image_stream.hdf5

HDF5 file containing raw imaging data:

```python
import tables

with tables.open_file('image_stream.hdf5', mode='r') as f:
    images = f.root.raw_images[:]  # Shape: (n_frames, height, width, channels)
```

---

## Configuration Schema

### Required Sections

```ini
[configsection]
config = section_name

[section_name]
# ... parameters
```

### Common Parameters

See [Configuration Reference](configuration.md) for complete parameter list.

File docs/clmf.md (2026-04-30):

# CLMF - Closed-Loop Movement Feedback

CLMF uses real-time pose estimation (DeepLabCut-Live) to provide audio feedback correlated with movement speed of a specified body part.

## How It Works

```
Camera → Pose Estimation → Speed Calculation → Threshold Check → Audio Feedback + Reward
```

1. **Pose Tracking**: DeepLabCut-Live infers body part positions
2. **Speed Calculation**: Compute movement speed between frames
3. **Feedback**: Map speed to audio tone frequency
4. **Reward**: Deliver water when speed exceeds threshold

## Running CLMF Experiments

```bash
python behavior/cla_dlc_trials_speed.py
```

## Configuration Parameters

### Required Settings (config.ini)

```ini
[sentech_dlclive]
vid_source = SentechCameraStream
data_root = /path/to/data/
dlc_model_path = /path/to/dlc-model/
resolution = 640, 320
framerate = 30
joint_history_sec = 5
ppmm = 3.5
bregma = 108, 128
control_point = fl_l
start_center = 590, 110
start_radius_mm = 4
target_center = 590, 80
target_radius_mm = 6
speed_threshold = 20
audio = 1
n_tones = 18
reward_threshold_mm = 5
adaptive_threshold = 0
total_trials = 10
max_trial_dur = 30
success_rest_dur = 10
fail_rest_dur = 10
initial_rest_dur = 30
```

### Parameter Reference

| Parameter | Description | Typical Value |
|---|---|---|
| `vid_source` | Camera driver | `SentechCameraStream` |
| `dlc_model_path` | DeepLabCut model directory | `/path/to/model/` |
| `resolution` | Image resolution | `640, 320` |
| `framerate` | Acquisition frame rate | `30` |
| `joint_history_sec` | History for stability check | `5` |
| `ppmm` | Pixels per millimeter | `3.5` |
| `control_point` | Body part to track | `fl_l`, `fl_r`, etc. |
| `start_center` | Start ROI center (pixels) | `590, 110` |
| `start_radius_mm` | Start ROI radius (mm) | `4` |
| `target_center` | Target ROI center (pixels) | `590, 80` |
| `target_radius_mm` | Target ROI radius (mm) | `6` |
| `speed_threshold` | Speed threshold (pixels/frame) | `20` |
| `n_tones` | Number of audio frequencies | `18` |
| `reward_threshold_mm` | Distance threshold for reward | `5` |
| `adaptive_threshold` | Auto-adjust threshold | `0` or `1` |

## Body Parts (DeepLabCut)

The system tracks all body parts defined in your DeepLabCut model. Common options:

- `fl_l` - Left forelimb
- `fl_r` - Right forelimb
- `hl_l` - Left hindlimb
- `hl_r` - Right hindlimb

## Trial Initialization Options

### Option 1: Stability-based (Default)

Trials start when the tracked body part is stable (not moving) for `joint_history_sec`:

```python
if np.mean(cj_speed_hist_que) < 1:  # stable
    start_trial()
```

### Option 2: Start ROI-based

Trials start when the body part is within the start ROI:

```python
if cj_start_dist < start_radius:
    start_trial()
```

### Option 3: Immediate (After Rest)

Trials start immediately after rest period ends:

```python
# Uncomment in code:
rest = False
runTrial = True
```

## Audio Feedback Mapping

Movement speed is mapped to audio frequency:

```
Speed = 0    →  1000 Hz (low tone)
Speed = threshold → 1000 × 2^(n_tones/4) Hz (high tone)
```

## Session Types

Configure in code:

```python
# Normal audio + normal reward
sessionType = clh.SessionType.normal_audio_normal_reward

# Single audio + normal reward (constant tone)
sessionType = clh.SessionType.single_audio_normal_reward

# No audio + random reward (control)
sessionType = clh.SessionType.no_audio_random_reward

# Normal audio + no reward (just feedback)
sessionType = clh.SessionType.normal_audio_no_reward

# No audio + no reward (control)
sessionType = clh.SessionType.no_audio_no_reward
```

## Adaptive Thresholding

When `adaptive_threshold = 1`:

- Every 30 seconds, check rewards in epoch
- If > 1 reward: increase speed threshold by 2
- If 0 rewards: decrease speed threshold by 2 (minimum 2)

## Hardware Setup

### Required Components

- Nvidia Jetson Orin (or equivalent GPU)
- Sentech camera (or USB3 camera)
- Arduino (for TTL and LED control)
- Water reward valve
- Audio speaker

### Arduino Pinout

| Pin | Function |
|-----|---|
| 13 | Brain TTL (output) |
| 7 | Reward LED |
| 12 | Fail LED |
| 40 | Light TTL |

### GPIO (RPi GPIO numbering)

| Pin | Function |
|-----|---|
| 13 | Brain TTL |
| 7 | Reward LED |
| 12 | Fail LED |
| 40 | Light TTL |

## Data Output

### Log File Format

```
frame	time	cj_speed	freq	reward	trial	audio	lick	pose_x	pose_y	likelihood...
```

### Pose Data

All DeepLabCut body parts are logged with x, y, and likelihood values.

### Summary CSV

```
mouse_id, session, data_path, start, end, duration, fps, n_tones, start_radius, target_radius, rewards, audio, session_type
```

## Example Workflow

1. Train DeepLabCut model on your setup
2. Configure `dlc_model_path` in `config.ini`
3. Set `control_point` to the body part to track
4. Calibrate `ppmm` (pixels per millimeter)
5. Run: `python behavior/cla_dlc_trials_speed.py`
6. Enter mouse ID when prompted
7. Adjust ROI positions in preview window
8. Press `Esc` to start session
9. Monitor real-time pose and speed
10. Press `Esc` to end or wait for completion

## Video Recording

The system records behavior video during sessions:

- Format: MP4
- Resolution: Matched to camera settings
- Frame rate: Matched to acquisition

## Troubleshooting

See [Troubleshooting Guide](troubleshooting.md) for common issues, including:
- DeepLabCut-Live initialization
- GPU memory management
- Pose estimation quality

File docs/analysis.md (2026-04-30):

# Data Analysis

CLoPy includes scripts for analyzing experimental data and recreating figures from the paper.

## Analysis Scripts

### Location

All analysis scripts are in the `analysis/` folder:

```
analysis/
├── get_clmf_data.py    # Load and process CLMF data
├── plot_clmf.py        # Generate CLMF figures
└── plot_clnf.py        # Generate CLNF figures
```

## CLNF Analysis

### Loading Data

```python
import helper as clh

# Load configuration from session
cfgDict = clh.GetConfigValues('/path/to/session/')
```

### Processing ΔF/F

The system calculates ΔF/F as:

```python
dff = (image - runningAvg) / runningAvg
dffCorrected = dffGreen - dffBlue  # Ratiometric correction
```

### Plotting Functions

```python
# Plot ROI activity over time
clh.plt_roi_activity(mouse_id, data_dir)

# Plot threshold crossings
clh.plt_threshold_crossings(mouse_id, data_dir)

# Plot spontaneous thresholds
clh.plt_spontaneous_thresholds(mouse_id, data_dir)
```

### Data Files

- `VideoTimestamp.txt`: Trial-by-trial log
- `image_stream.hdf5`: Raw imaging data
- `config.ini`: Session configuration

### VideoTimestamp.txt Format (CLNF)

```
frame	time	roi_dff	freq	rew_threshold	reward	trial	audio	lick
```

## CLMF Analysis

### Loading Pose Data

```python
import pandas as pd

# Load trial log
df = pd.read_csv('/path/to/session/log.txt', sep='\t')

# Access pose data
pose_cols = [col for col in df.columns if '_x' in col or '_y' in col]
```

### Calculating Speed

```python
import math

# Calculate speed between frames
speed = math.dist(prev_pos, curr_pos)
```

### Plotting Functions

```python
# In plot_clmf.py
import matplotlib.pyplot as plt

# Plot trial outcomes
plt.figure()
plt.plot(df['trial'], df['reward'])

# Plot speed over time
plt.figure()
plt.plot(df['cj_speed'])
```

### VideoTimestamp.txt Format (CLMF)

```
frame	time	cj_speed	freq	reward	trial	audio	lick	pose_x	pose_y	likelihood...
```

## Preprocessed Data

Place CSV files in `processed_data/` to recreate figures:

```
processed_data/
├── clmf_kld_df.csv
├── clmf_sessions_df.csv
├── clmf_trials_df.csv
└── clnf_sessions_df.csv
```

## Example: Plot Session Summary

```python
import pandas as pd
import matplotlib.pyplot as plt

# Load summary data
df = pd.read_csv('processed_data/clnf_sessions_df.csv')

# Plot reward rate over sessions
plt.figure(figsize=(10, 6))
for mouse in df['mouse_id'].unique():
    mouse_data = df[df['mouse_id'] == mouse]
    plt.plot(mouse_data['session'], mouse_data['rewards'], label=mouse)

plt.xlabel('Session')
plt.ylabel('Total Rewards')
plt.legend()
plt.title('Learning Curve')
plt.show()
```

## Statistical Analysis

### Reward Rate Calculation

```python
# Calculate rewards per minute
sess_dur_min = duration / 60
reward_rate = total_rewards / sess_dur_min
```

### Threshold Optimization

```python
# Find threshold for target reward rate
def find_threshold(dff_values, target_rate):
    for thresh in np.arange(0, 0.2, 0.001):
        rate = sum(dff_values > thresh) / sess_dur_min
        if rate <= target_rate:
            return thresh
    return None
```

## Exporting Data

### To CSV

```python
df.to_csv('output.csv', index=False)
```

### To HDF5

```python
import tables

with tables.open_file('output.hdf5', mode='w') as f:
    f.create_earray(f.root, 'data', obj=array)
```

## Creating Figures

See the paper for figure recreation scripts. Key plots include:

1. **Reward-centered dorsal maps**: Average activity around reward times
2. **Learning curves**: Rewards per session over training
3. **Trial timing**: Distribution of trial durations
4. **Threshold distributions**: Adaptive threshold values

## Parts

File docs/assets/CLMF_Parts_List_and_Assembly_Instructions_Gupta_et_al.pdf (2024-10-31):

### Pankaj Gupta¹,2

### , Timothy H. Murphy¹,2,*

# Closed-Loop Movement Feedback (CLMF) NVIDIA-JETSON BEHAVIOR IMAGING RIG

# PART LIST

## TRIPLE LED LIGHT GUIDE

### Bought Parts

Manufacturer | Name | Part ID | Quantity
Thorlabs | Liquid Light Guide Ø3 mm Core | LLG0338-4 | 1
Thorlabs | SM1 Lens Tube, 3.00" Thread Depth, One Retaining Ring Included | SM1L30 | 3
Thorlabs | SM1 Lens Tube, 0.50" Thread Depth, One Retaining Ring Included | SM1L05 | 3
Thorlabs | SM1 Lens Tube, 2.00" Thread Depth, One Retaining Ring Included | SM1L20 | 1
Thorlabs | f=30.0 mm, Ø1" Achromatic Doublet, ARC: 400-700 nm | AC254-030-A | 1
Thorlabs | N-BK7 Bi-Convex Lens, Ø1", f = 25.4 mm, Uncoated | LB1761 | 3
Thorlabs | Ø3 mm LLG to SM1 Adapter | AD3LLG | 1
Thorlabs | 30 mm Cage Cube with Dichroic Filter Mount | CM1-DCH | 2
Thorlabs | Cage Cube Connector for Compact 30 mm Cage Cubes | CM1-CC | 1
Thorlabs | 25 mm x 36 mm Longpass Dichroic Mirror, 550 nm Cutoff | DMLP550R | 1
Thorlabs | Ø1" Laser Line Filter, CWL = 635 ± 2 nm, FWHM = 10 ± 2 nm | FL635-10 | 1
Thorlabs | Ø1" Bandpass Filter, CWL = 440 ± 2 nm, FWHM = 10 ± 2 nm | FB440-10 | 1
Thorlabs | SM1 Retaining Ring for Ø1" Lens Tubes and Mounts, 10 Pack | SM1RR-P10 | 1
Chroma | AT455DC Size: 26 * 38 mm | AT455DC | 1
Chroma | ET480/30x Size: 25mmR R=Mounted in Ring | ET480/30x | 1
Luxeonstar | Royal-Blue (448nm) Rebel LED on a SinkPAD-II 20mm Star Base - 1030 mW @ 700mA | SP-01-V4 | 1
Luxeonstar | Blue (470nm) Rebel LED on a SinkPAD-II 10mm Square Base -65 lm @ 700mA | SP-05-B4 | 1
Luxeonstar | Red (627nm) Rebel LED on a SinkPAD-II 20mm Star Base - 64 lm @ 350mA | SP-01-D9 | 1

### Machined Parts

File Name | Quantity

Milled as-1.50_2_v2.SLDPRT | 3
Spacer_with_wire_hole_as-.500_v2.SLDPRT | 3
LED_mount_as-1.50_v2.SLDPRT | 3

### 3D Printed Parts

File Name | Quantity
TripleLEDLightGuide_Base.stl | 1

## RIG

### Purchased Parts

Manufacturer | Name | Part ID | Quantity
N/A | ¼-20 Set Screws, Bolts, Nuts, Washers; M2 Screws, Nuts | N/A | Enough
N/A | 1.5 Inch Outer Diameter 1 ⅛ Inch Inner Diameter Acrylic Tubing | N/A | 4 Inch Length
Thorlabs | Clamping Fork, 1.24" Counterbored Slot, Universal | CF125 | 2
Thorlabs | Ø1/2" Pedestal Post Holder, Spring-Loaded Hex-Locking Thumbscrew, L=1.19" | PH1E | 2
Thorlabs | Ø1/2" Optical Post, SS, 8-32 Setscrew, 1/4"-20 Tap, L = 4" | TR4 | 1
Thorlabs | Ø1/2" Optical Post, SS, 8-32 Setscrew, 1/4"-20 Tap, L = 6" | TR6 | 1
Thorlabs | Ø1/2" Optical Post, SS, 8-32 Setscrew, 1/4"-20 Tap, L = 1.5" | TR1.5 | 2
Thorlabs | Compact Variable Height Clamp, 1/4"-20 Tapped | CL3 | 2
Edmund Optics | 6" x 6", Breadboard | #56-930 | 1
Edmund Optics | 12" x 12", Breadboard | #53-830 | 1
Edmund Optics | 4" Length, ¼-20 Thread, Post Holder | #58-980 | 1
Edmund Optics | Right Angle Post Clamps | #53-357 | 1
Edmund Optics | 12.7mm - 12.7mm (Rotatable), Right Angle Post Clamp | #58-994 | 1
Siskiyou | AS-.500 Aluminium Spacer 0.5 Inches Package of 4 | 60400000E | 1
Siskiyou | AS-2.00 Aluminium Spacer 2 Inches Package of 4 | 60430000E | 1
Sherline | Vertical Milling Column | 3050 | 1

### Machined Parts

File Name | Quantity
BarClamp_V.SLDPRT | 2
Clamp.SLDPRT | 2

### 3D Printed Parts

File Name | Quantity
TubeHolder_Even.stl | 1
Camera_Holder_Mark_II.stl | 1
Light Guide Mount_MarkII.stl | 1
4PiTower.stl | 1
BehaviourCameraArms.stl | 1

## Electronics

Manufacturer | Name | Part ID | Quantity
Sparkfun | Hook-Up Wire - Assortment (Stranded, 22 AWG) | 11375 | 1
RaspberryPi | NVIDIA Jetson Orin (8-core ARM Cortex CPU, 2048 CUDA cores, 64 GB memory) | N/A | 1
Omron Sentech | STC-MCCM401U3V USB3 Vision camera | N/A | 1
Teledyne Dalsa | DS-21-01M60 | N/A | 1
N/A | LED Driver | N/A | 2
Logitech | Logitech Speaker System S120 | LOG980000010 | 1

## ASSEMBLY OF THE CLNF RIG Triple LED Light Guide Assembly

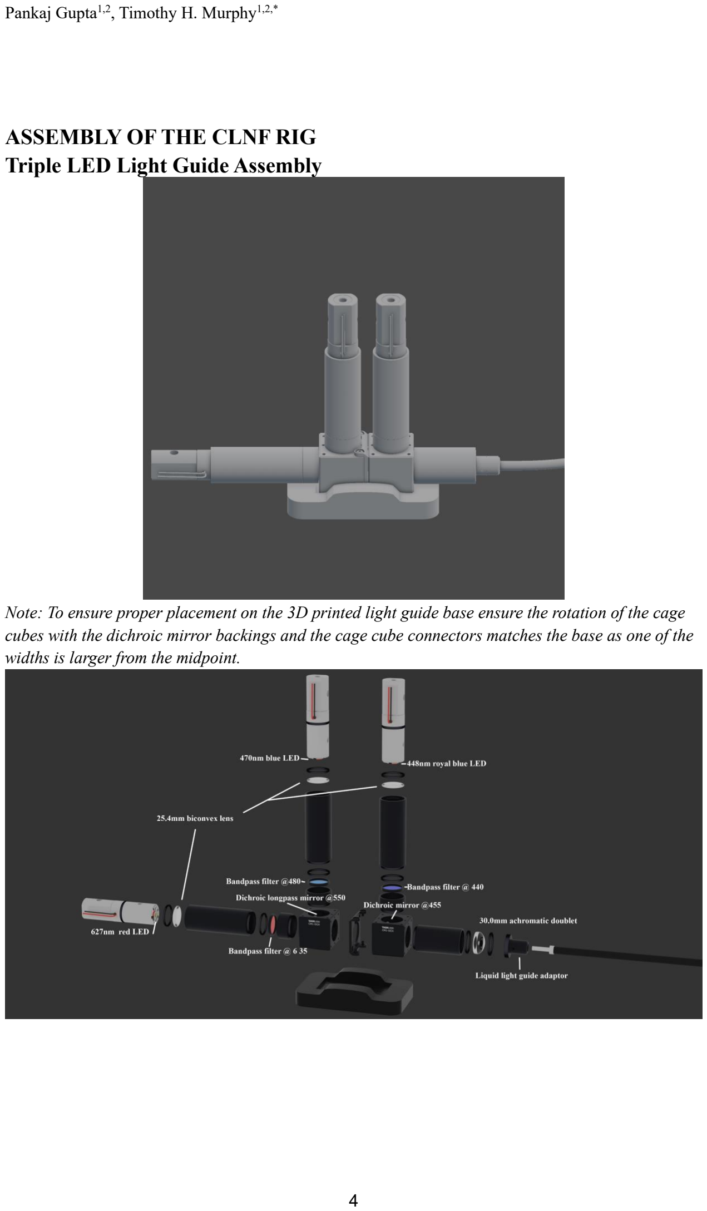
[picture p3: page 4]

Note: To ensure proper placement on the 3D printed light guide base ensure the rotation of the cage cubes with the dichroic mirror backings and the cage cube connectors matches the base as one of the widths is larger from the midpoint.

## Platform Setup

1) Drill 2 countersink holes at the edge of the 12 inch by 12 inch breadboard.

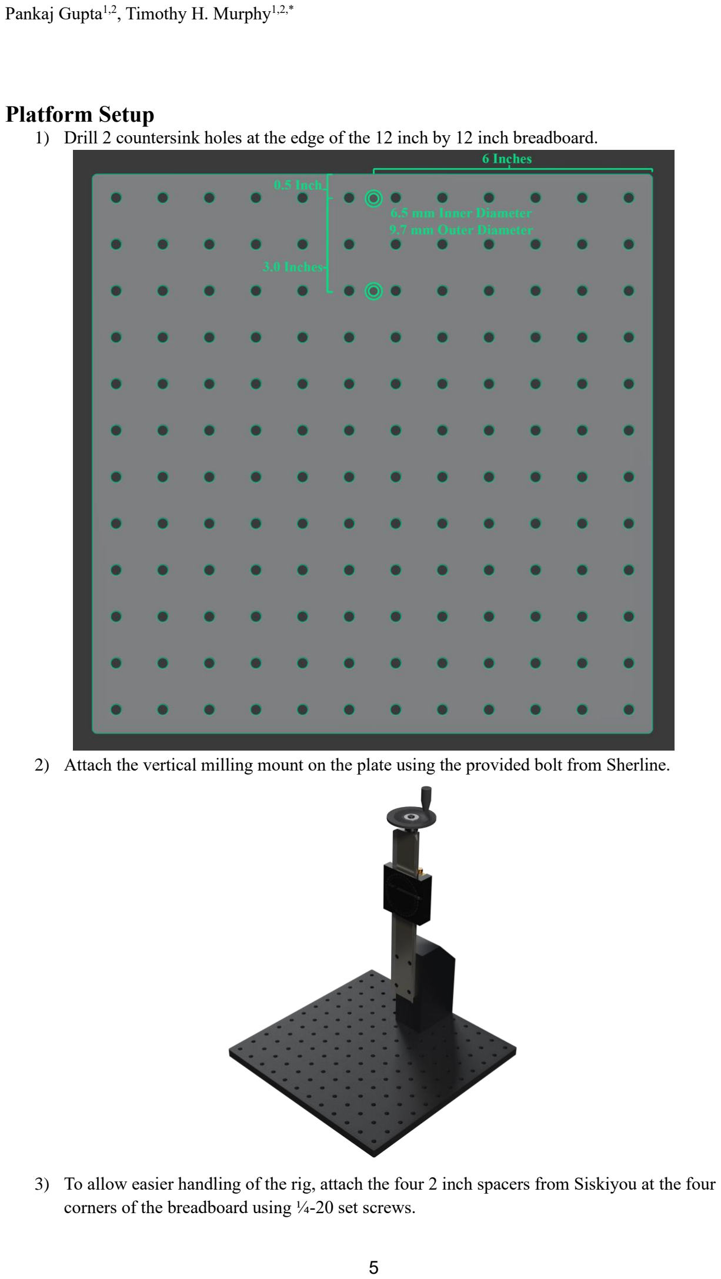
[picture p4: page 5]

2) Attach the vertical milling mount on the plate using the provided bolt from Sherline.
3) To allow easier handling of the rig, attach the four 2 inch spacers from Siskiyou at the four corners of the breadboard using ¼-20 set screws.

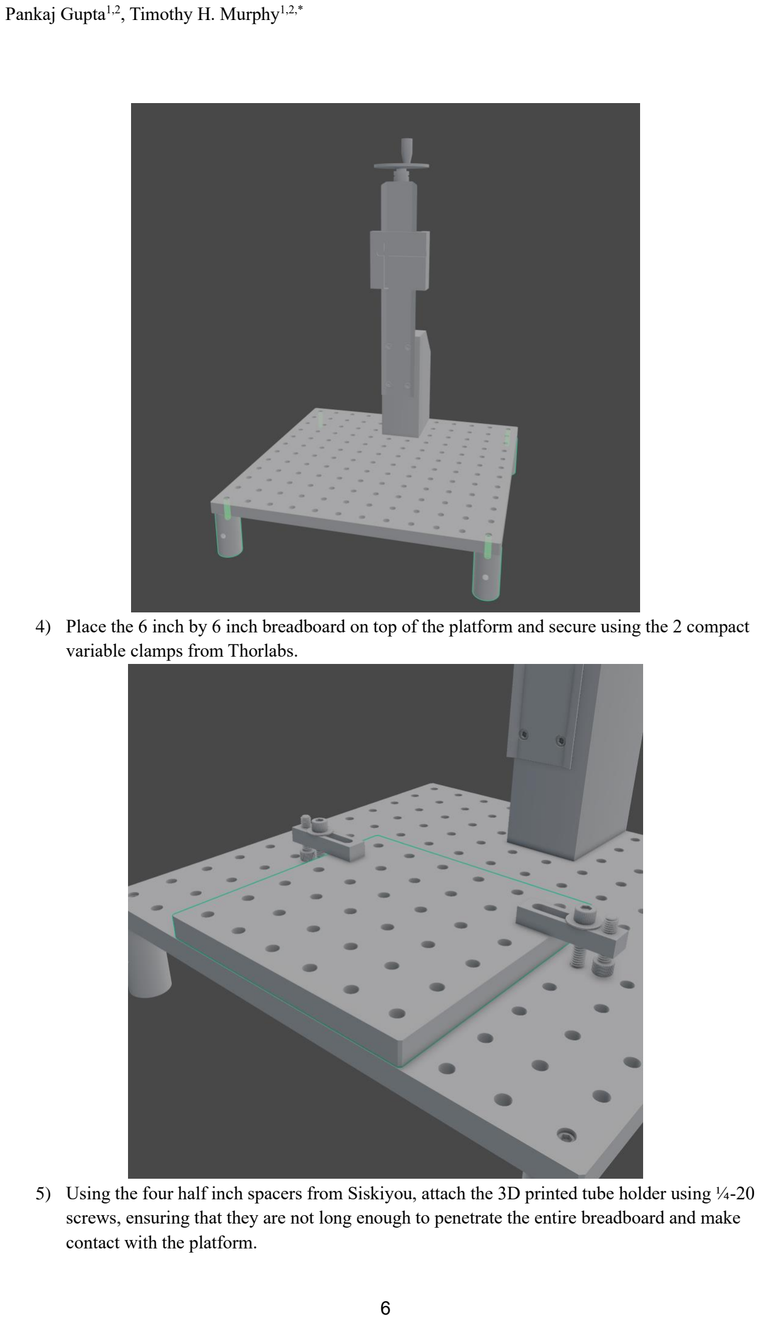
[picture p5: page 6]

4) Place the 6 inch by 6 inch breadboard on top of the platform and secure using the 2 compact variable clamps from Thorlabs.
5) Using the four half inch spacers from Siskiyou, attach the 3D printed tube holder using ¼-20 screws, ensuring that they are not long enough to penetrate the entire breadboard and make contact with the platform.

## 6) Custom made headfixing chamber parts. Design files for laser cutting parts from a plexiglass sheet as shown below included in the repository. A mirror was inserted in

the angled slot of part 4 and part 5 to image the bottom of the mouse in side view.

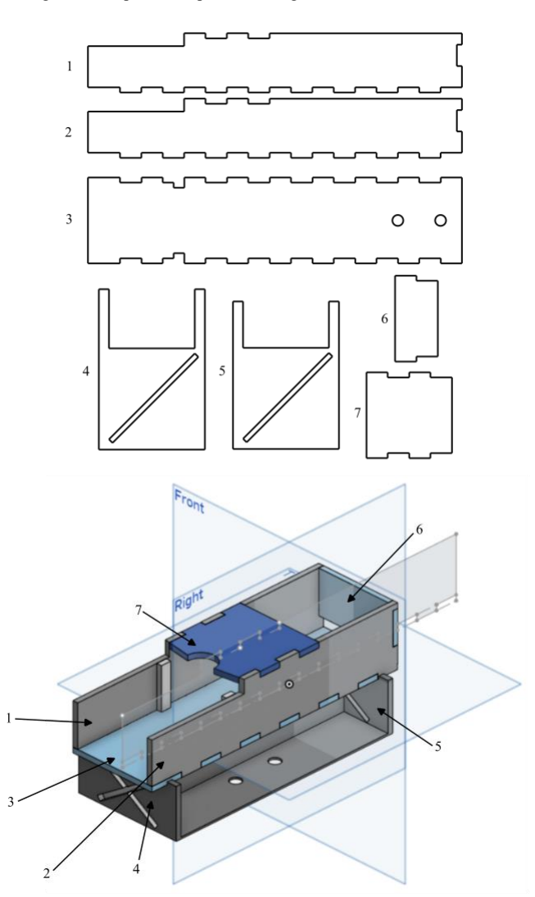
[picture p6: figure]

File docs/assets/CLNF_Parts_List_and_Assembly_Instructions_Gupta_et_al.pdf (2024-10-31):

### Pankaj Gupta¹,2

### , Timothy H. Murphy¹,2,*

# Closed-Loop Neurofeedback (CLNF) RASPBERRY-PI WIDEFIELD IMAGING RIG

# PART LIST

## TRIPLE LED LIGHT GUIDE

### Bought Parts

Manufacturer | Name | Part ID | Quantity
Thorlabs | Liquid Light Guide Ø3 mm Core | LLG0338-4 | 1
Thorlabs | SM1 Lens Tube, 3.00" Thread Depth, One Retaining Ring Included | SM1L30 | 3
Thorlabs | SM1 Lens Tube, 0.50" Thread Depth, One Retaining Ring Included | SM1L05 | 3
Thorlabs | SM1 Lens Tube, 2.00" Thread Depth, One Retaining Ring Included | SM1L20 | 1
Thorlabs | f=30.0 mm, Ø1" Achromatic Doublet, ARC: 400-700 nm | AC254-030-A | 1
Thorlabs | N-BK7 Bi-Convex Lens, Ø1", f = 25.4 mm, Uncoated | LB1761 | 3
Thorlabs | Ø3 mm LLG to SM1 Adapter | AD3LLG | 1
Thorlabs | 30 mm Cage Cube with Dichroic Filter Mount | CM1-DCH | 2
Thorlabs | Cage Cube Connector for Compact 30 mm Cage Cubes | CM1-CC | 1
Thorlabs | 25 mm x 36 mm Longpass Dichroic Mirror, 550 nm Cutoff | DMLP550R | 1
Thorlabs | Ø1" Laser Line Filter, CWL = 635 ± 2 nm, FWHM = 10 ± 2 nm | FL635-10 | 1
Thorlabs | Ø1" Bandpass Filter, CWL = 440 ± 2 nm, FWHM = 10 ± 2 nm | FB440-10 | 1
Thorlabs | SM1 Retaining Ring for Ø1" Lens Tubes and Mounts, 10 Pack | SM1RR-P10 | 1
Chroma | AT455DC Size: 26 * 38 mm | AT455DC | 1
Chroma | ET480/30x Size: 25mmR R=Mounted in Ring | ET480/30x | 1
Luxeonstar | Royal-Blue (448nm) Rebel LED on a SinkPAD-II 20mm Star Base - 1030 mW @ 700mA | SP-01-V4 | 1
Luxeonstar | Blue (470nm) Rebel LED on a SinkPAD-II 10mm Square Base -65 lm @ 700mA | SP-05-B4 | 1
Luxeonstar | Red (627nm) Rebel LED on a SinkPAD-II 20mm Star Base - 64 lm @ 350mA | SP-01-D9 | 1

### Machined Parts

File Name | Quantity
Milled as-1.50_2_v2.SLDPRT | 3
Spacer_with_wire_hole_as-.500_v2.SLDPRT | 3

LED_mount_as-1.50_v2.SLDPRT | 3

### 3D Printed Parts

File Name | Quantity
TripleLEDLightGuide_Base.stl | 1

## RIG

### Purchased Parts

Manufacturer | Name | Part ID | Quantity
N/A | ¼-20 Set Screws, Bolts, Nuts, Washers; M2 Screws, Nuts | N/A | Enough
N/A | 1.5 Inch Outer Diameter 1 ⅛ Inch Inner Diameter Acrylic Tubing | N/A | 4 Inch Length
Thorlabs | Clamping Fork, 1.24" Counterbored Slot, Universal | CF125 | 2
Thorlabs | Ø1/2" Pedestal Post Holder, Spring-Loaded Hex-Locking Thumbscrew, L=1.19" | PH1E | 2
Thorlabs | Ø1/2" Optical Post, SS, 8-32 Setscrew, 1/4"-20 Tap, L = 4" | TR4 | 1
Thorlabs | Ø1/2" Optical Post, SS, 8-32 Setscrew, 1/4"-20 Tap, L = 6" | TR6 | 1
Thorlabs | Ø1/2" Optical Post, SS, 8-32 Setscrew, 1/4"-20 Tap, L = 1.5" | TR1.5 | 2
Thorlabs | Compact Variable Height Clamp, 1/4"-20 Tapped | CL3 | 2
Edmund Optics | 6" x 6", Breadboard | #56-930 | 1
Edmund Optics | 12" x 12", Breadboard | #53-830 | 1
Edmund Optics | 4" Length, ¼-20 Thread, Post Holder | #58-980 | 1
Edmund Optics | Right Angle Post Clamps | #53-357 | 1
Edmund Optics | 12.7mm - 12.7mm (Rotatable), Right Angle Post Clamp | #58-994 | 1
Siskiyou | AS-.500 Aluminium Spacer 0.5 Inches Package of 4 | 60400000E | 1
Siskiyou | AS-2.00 Aluminium Spacer 2 Inches Package of 4 | 60430000E | 1
Sherline | Vertical Milling Column | 3050 | 1

### Machined Parts

File Name | Quantity
BarClamp_V.SLDPRT | 2
Clamp.SLDPRT | 2

### 3D Printed Parts

File Name | Quantity
TubeHolder_Even.stl | 1
Camera_Holder_Mark_II.stl | 1
Light Guide Mount_MarkII.stl | 1

4PiTower.stl | 1
BehaviourCameraArms.stl | 1

## Electronics

Manufacturer | Name | Part ID | Quantity
Sparkfun | Hook-Up Wire - Assortment (Stranded, 22 AWG) | 11375 | 1
RaspberryPi | Raspberry Pi Model 4B+ | N/A | 2
Waveshare | RPi Camera (B), Adjustable-Focus | RPi Camera (B) | 1
Waveshare | RPi Camera (F), Supports Night Vision, Adjustable-Focus | RPi Camera (F) | 1
N/A | LED Driver | N/A | 2
Logitech | Logitech Speaker System S120 | LOG980000010 | 1

## ASSEMBLY OF THE CLNF RIG Triple LED Light Guide Assembly

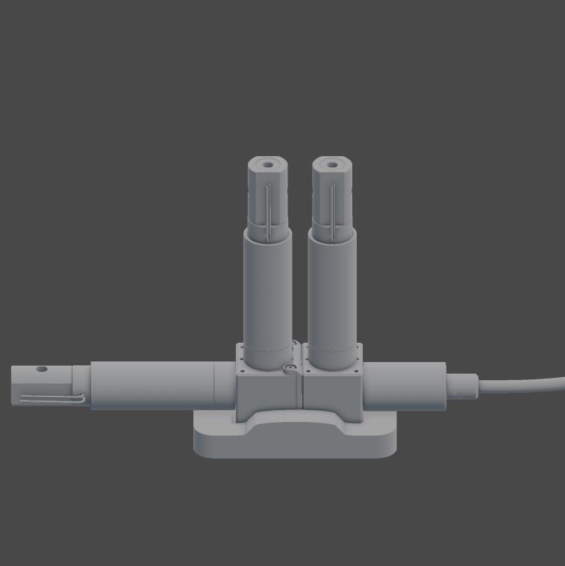
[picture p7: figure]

Note: To ensure proper placement on the 3D printed light guide base ensure the rotation of the cage cubes with the dichroic mirror backings and the cage cube connectors matches the base as one of the widths is larger from the midpoint.

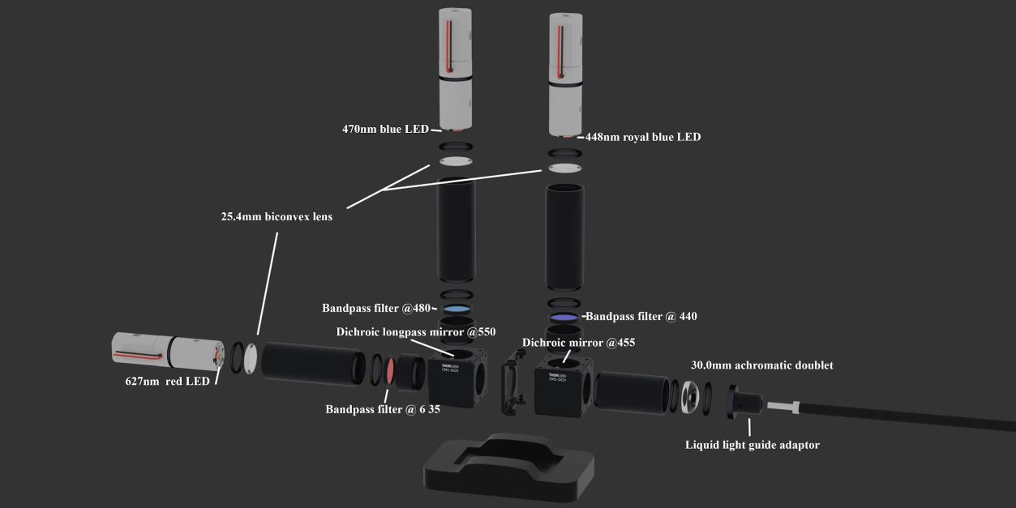
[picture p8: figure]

## Platform Setup

1) Drill 2 countersink holes at the edge of the 12 inch by 12 inch breadboard.

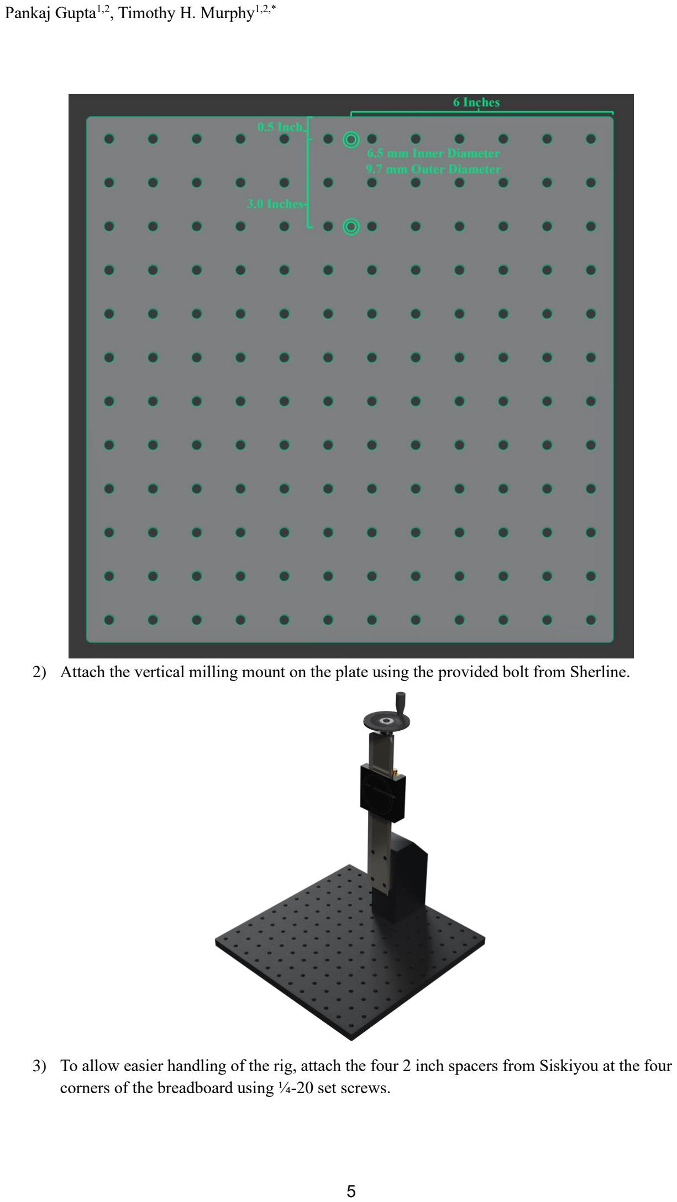
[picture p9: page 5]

2) Attach the vertical milling mount on the plate using the provided bolt from Sherline.
3) To allow easier handling of the rig, attach the four 2 inch spacers from Siskiyou at the four corners of the breadboard using ¼-20 set screws.


4) Place the 6 inch by 6 inch breadboard on top of the platform and secure using the 2 compact variable clamps from Thorlabs.
5) Using the four half inch spacers from Siskiyou, attach the 3D printed tube holder using ¼-20 screws, ensuring that they are not long enough to penetrate the entire breadboard and make contact with the platform.

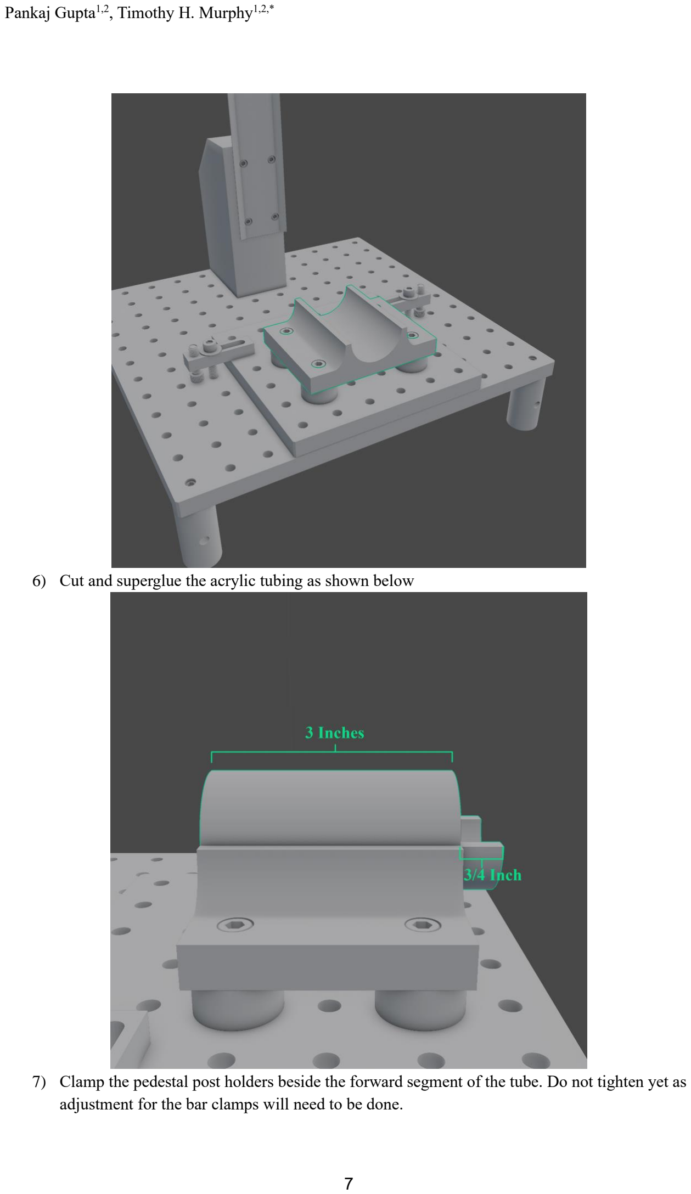
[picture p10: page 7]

### 6) Cut and superglue the acrylic tubing as shown below

7) Clamp the pedestal post holders beside the forward segment of the tube. Do not tighten yet as adjustment for the bar clamps will need to be done.


8) Assemble the bar clamps and attach them to the 1.5 inch posts and place them on the pedestal post holders. At this point you can bring a bar to adjust the location of the fork clamps.
9) Using a ¼-20 set screw, attach the 4 inch post holder to the vertical milling mount and place the 6 ½ inch post in it.


10) The liquid light guide will be projecting from the back of the mouse’s head and will be attached using the 3D printed adaptor that has an 8/32 nut and bolt attached to it for securing the guide as shown below. You can super glue the nut in, ensuring that it does not slip into the guide’s hole and prevents it from being slipped in.


11) The adaptor will be held in place using the rotatable clamp and right angle clamp from Edmund Optics with the 4 inch ½ inch post connecting them as shown below.


12) The camera mount will have a similar setup to the light guide adaptor in which you will need

### to superglue a ¼-20 nut to allow the fixation of the mount on the post. Attach the camera

using 4 M2 screws (you may have to drill the holes on the camera board to match as they are

### made pretty small)


13) Attach the camera mount onto the ½ inch post and secure tightly. Due to the mismatched widths of the right angle clamp and rotatable clamp, you will have to rotate the right angle clamp so the light guide can come straight from the back.


14) Attach the light guide to the mount and secure using the 8/32 bolt. A render of the completed rig is shown below.

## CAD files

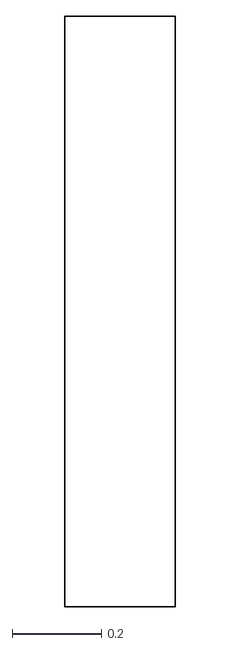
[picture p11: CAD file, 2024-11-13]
3D-print/MouseHeadFixPost.dxf
0.247 x 1.32

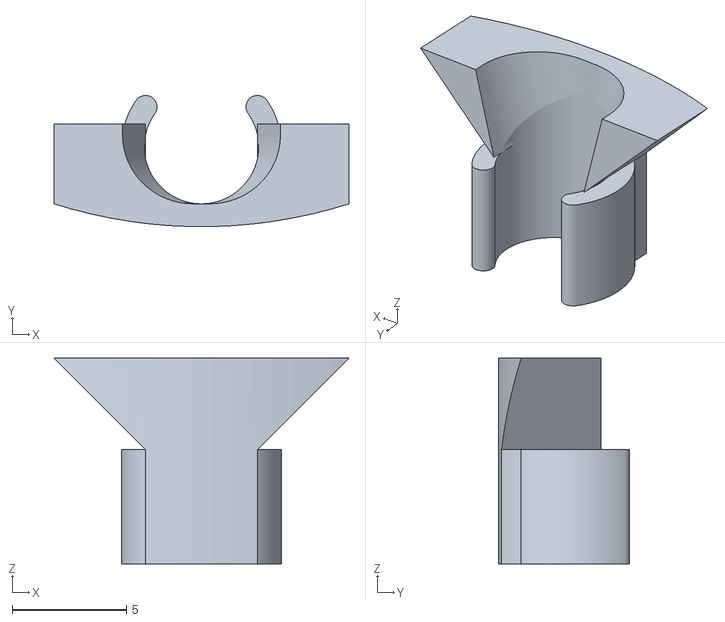
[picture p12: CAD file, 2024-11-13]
3D-print/light-funnel.stl
12.9 x 5.73 x 9.00

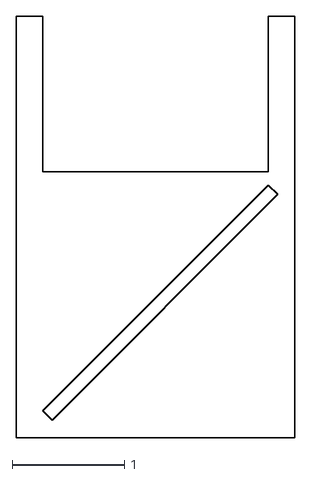
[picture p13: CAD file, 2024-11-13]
3D-print/MirrorHolderRear.dxf
2.48 x 3.75

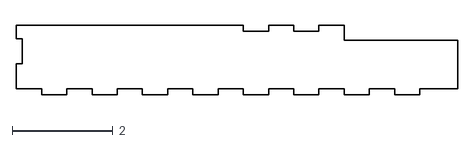
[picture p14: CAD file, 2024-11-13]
3D-print/MouseHolderSide.dxf
8.75 x 1.39

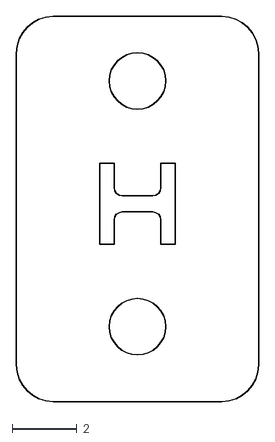
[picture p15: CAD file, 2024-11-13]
3D-print/MouseEnclosureTop.dxf
7.50 x 11.9

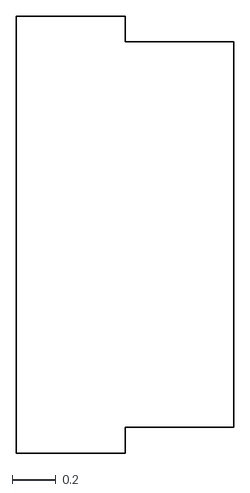
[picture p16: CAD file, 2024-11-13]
3D-print/MouseHeadFixBack.dxf
1 x 2.01

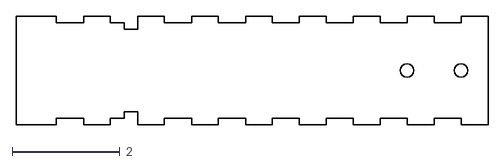
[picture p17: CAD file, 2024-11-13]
3D-print/MouseHeadFixBottom.dxf
8.75 x 2.01

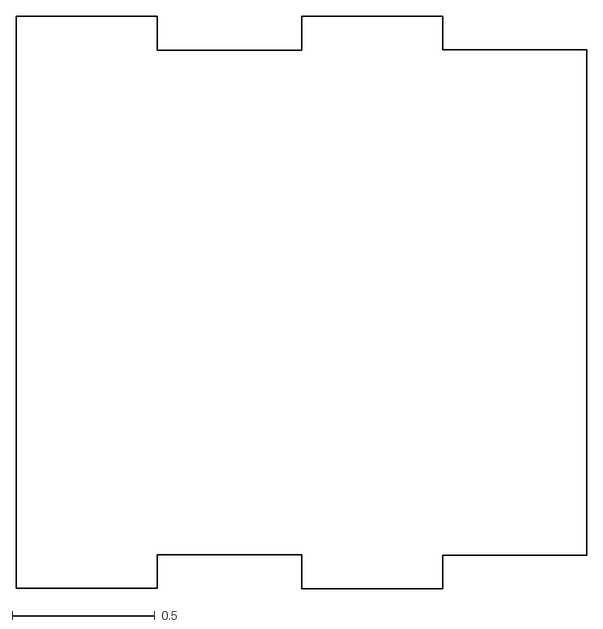
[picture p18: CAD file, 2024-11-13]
3D-print/MouseHeadFixTop.dxf
2.00 x 2.01

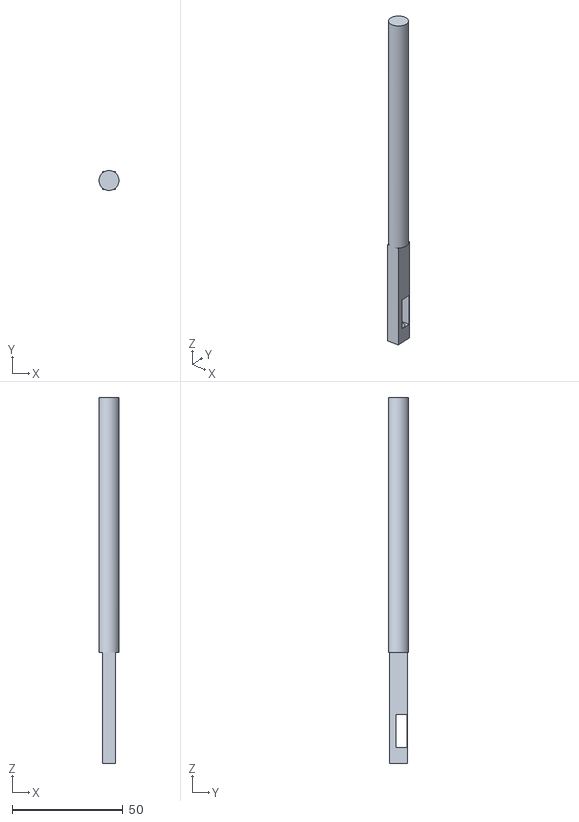
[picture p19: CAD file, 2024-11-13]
3D-print/spoutholder.stl
9.00 x 8.99 x 165.0

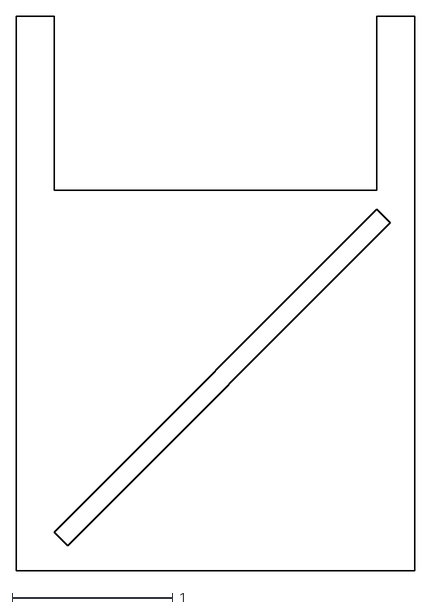
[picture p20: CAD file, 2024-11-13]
3D-print/MirrorHolderFront.dxf
2.48 x 3.45

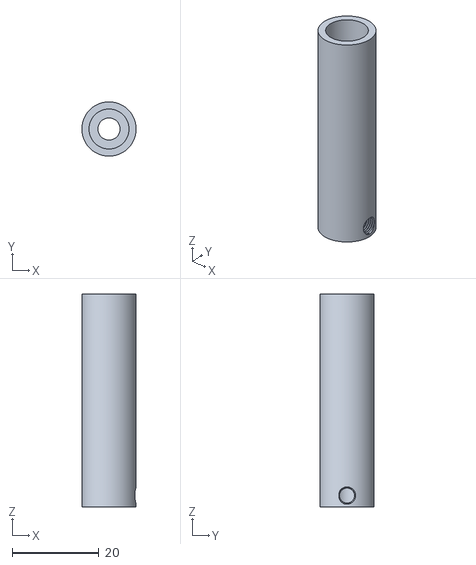
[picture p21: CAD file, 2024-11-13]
3D-print/liquid-light-guide-holder.stl
12.5 x 12.5 x 49.0

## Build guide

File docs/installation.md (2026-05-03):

# Installation Guide

This guide covers installation of CLoPy on your system. Choose the appropriate section based on your experiment type (CLNF or CLMF).

!!! warning "Platform Requirements"
    - **CLNF**: Raspberry Pi 4B+ (recommended)
    - **CLMF**: Nvidia Jetson Orin with GPU (required for DeepLabCut-Live)

## Prerequisites

- Python >= 3.8
- [Anaconda](https://docs.anaconda.com/anaconda/install/) or [Miniconda](https://docs.anaconda.com/miniconda/miniconda-install/) (recommended)

## Step 1: Create Environment

```bash
conda create -n clopy
conda activate clopy
```

## Step 2: Install Core Dependencies

```bash
pip3 install opencv-python tables cvui roipoly scipy pandas joblib pillow videofig imutils
```

## Step 3: Install Audio Dependencies

### Install PyAudio

#### Linux (Debian/Ubuntu)

```bash
sudo apt-get install portaudio19-dev python3-pyaudio
pip3 install PyAudio
```

#### macOS

```bash
brew install portaudio
pip3 install PyAudio
```

#### Windows

Download PyAudio from [Christophe Gauthier's site](https://people.csail.mit.edu/hubert/pyaudio/) or use:

```bash
pip3 install PyAudio
```

### Install Audiostream

#### Linux (Debian/Ubuntu)

```bash
sudo apt-get install libsdl1.2-dev
sudo apt-get install libsdl-mixer1.2-dev
pip3 install cython==0.29.21
pip3 install kivy
```

#### macOS/Windows

Follow [Kivy installation guide](https://kivy.org/doc/stable/gettingstarted/installation.html)

```bash
# Clone audiostream repository
git clone https://github.com/kivy/audiostream.git
cd audiostream
python setup.py install
```

## Step 4: Install Hardware-Specific Dependencies

### For CLNF (Raspberry Pi)

```bash
pip3 install gpiozero Adafruit-Blinka adafruit-circuitpython-mpr121
```

### For CLMF (Jetson Orin)

```bash
pip install deeplabcut-live
```

!!! important "DeepLabCut-Live"
    Please check the [DeepLabCut-Live GitHub page](https://github.com/DeepLabCut/DeepLabCut-live) for the latest installation instructions and TensorFlow version requirements.

## Step 5: Clone CLoPy Repository

```bash
cd ~
git clone https://github.com/pankajkgupta/clopy.git
cd clopy
```

## Step 6: Configure Hardware

### Raspberry Pi I2C Setup

1. Enable I2C interface:
   ```bash
   sudo raspi-config
   ```
   Navigate to `Interface Options` → `I2C` → `Enable`

2. Install I2C tools:
   ```bash
   sudo apt-get install i2c-tools
   ```

### Arduino Setup (for CLMF)

- Connect Arduino via USB
- Note the serial port (typically `/dev/ttyACM0`)

## Verification

Test your installation:

```python
import cv2
import numpy as np
from configparser import ConfigParser

print("Core packages imported successfully!")
```

## Next Steps

- [Quick Start Guide](quickstart.md)
- [CLNF Configuration](clnf.md)
- [CLMF Configuration](clmf.md)

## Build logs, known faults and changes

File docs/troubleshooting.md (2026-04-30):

# Troubleshooting Guide

Solutions to common issues encountered when running CLoPy experiments.

## Installation Issues

### PyAudio Installation Fails

**Symptom**: `pip install PyAudio` fails

**Solution**:
=== "Linux"
    ```bash
    sudo apt-get install portaudio19-dev python3-pyaudio
    pip3 install --no-cache-dir PyAudio
    ```

=== "Windows"
    Download precompiled wheel from [Christophe Gauthier's site](https://people.csail.mit.edu/hubert/pyaudio/)

### Audiostream Installation Fails

**Symptom**: `python setup.py install` fails

**Solution**:
```bash
# Install dependencies first
sudo apt-get install libsdl1.2-dev libsdl-mixer1.2-dev
pip3 install cython==0.29.21 kivy
```

### DeepLabCut-Live Import Error

**Symptom**: `ImportError: No module named 'dlclive'`

**Solution**:
```bash
# Check TensorFlow version compatibility
pip install tensorflow==2.10.0  # or compatible version
pip install deeplabcut-live
```

## Camera Issues

### PiCamera Not Detected

**Symptom**: Camera not found or black images

**Solution**:
1. Enable camera interface:
   ```bash
   sudo raspi-config
   ```
   → Interface Options → Camera → Enable

2. Check camera connection:
   ```bash
   raspistill -o test.jpg
   ```

3. Verify device:
   ```bash
   ls -la /dev/video*
   ```

### Sentech Camera Not Working

**Symptom**: No image or errors

**Solution**:
1. Check USB connection:
   ```bash
   v4l2-ctl --list-devices
   ```

2. Test with GST:
   ```bash
   gst-launch-1.0 v4l2src device=/dev/video0 ! videoconvert ! ximagesink
   ```

3. Check resolution compatibility in `config.ini`

## CLNF-Specific Issues

### ΔF/F Values Too High/Low

**Symptom**: Activity values outside expected range

**Solution**:
- Adjust `dff_history` (more frames = more stable baseline)
- Check `roi_size` is appropriate
- Verify `ppmm` calibration
- Adjust `reward_threshold` accordingly

### ROI Not Visible in Preview

**Symptom**: Cannot see ROI rectangles

**Solution**:
1. Check `seeds_mm` contains valid brain region
2. Verify `bregma` coordinates are correct
3. Ensure `roi_size` is not zero
4. Check camera is imaging correct area

### Audio Not Playing

**Symptom**: No audio feedback during trials

**Solution**:
1. Check `audio = 1` in config
2. Verify speaker is connected
3. Test audio independently:
   ```python
   from audiostream import get_output
   from audiostream.sources.wave import SineSource
   stream = get_output(channels=1, rate=44100)
   source = SineSource(stream, 1000)
   source.start()
   ```

### Lick Detection Not Working

**Symptom**: No lick detection even when mouse licks

**Solution**:
1. Check I2C connection:
   ```bash
   sudo i2cdetect -y 1
   ```
   Should show device at `0x5a`

2. Verify wiring (SCL, SDA, VCC, GND)

3. Test MPR121:
   ```python
   import board
   import busio
   import adafruit_mpr121
   i2c = busio.I2C(board.SCL, board.SDA)
   cap = adafruit_mpr121.MPR121(i2c)
   print(cap[0].value)  # Should change on touch
   ```

## CLMF-Specific Issues

### DeepLabCut-Live Initialization Fails

**Symptom**: Error loading model

**Solution**:
1. Verify model path exists:
   ```bash
   ls -la /path/to/dlc-model/
   ```

2. Check model format (should contain `*.pb` files)

3. Verify TensorFlow version:
   ```bash
   pip list | grep tensorflow
   ```

4. Try with display=False:
   ```python
   dlc_live = DLCLive(model_path, display=False)
   ```

### Pose Estimation Very Slow

**Symptom**: Low FPS, cannot keep up with camera

**Solution**:
1. Use GPU acceleration (Jetson Orin)
2. Reduce input resolution
3. Use smaller model
4. Check for memory issues:
   ```python
   import gc
   gc.collect()
   ```

### Body Part Not Tracking

**Symptom**: No pose data or NaN values

**Solution**:
1. Verify `control_point` exists in model:
   ```python
   print(dlc_live.cfg['all_joints_names'])
   ```

2. Check model was trained on that body part

3. Ensure body part is visible in frame

4. Adjust confidence threshold if needed

### Speed Values Too High/Low

**Symptom**: Speed always above/below threshold

**Solution**:
- Calibrate `ppmm` (pixels per millimeter)
- Adjust `speed_threshold` in config
- Check camera resolution matches config

## Data Issues

### HDF5 File Not Writing

**Symptom**: Error creating or writing to `.hdf5` file

**Solution**:
1. Check write permissions:
   ```bash
   ls -la /path/to/data/
   ```

2. Ensure directory exists:
   ```python
   os.makedirs(data_root, exist_ok=True)
   ```

3. Check disk space

### Log File Format Error

**Symptom**: Cannot read VideoTimestamp.txt

**Solution**:
- Check delimiter (tab-separated)
- Verify column names match expected
- Handle missing values appropriately

## Performance Issues

### Low Frame Rate

**Symptom**: FPS much lower than configured

**Solution**:
1. Reduce processing load:
   - Smaller ROI
   - Lower resolution
   - Fewer audio tones

2. Optimize code:
   - Use numpy operations
   - Avoid unnecessary copies

3. Check hardware:
   - SD card speed (use fast card)
   - CPU throttling (check `vcgencmd get_throttled`)

### Memory Errors

**Symptom**: `MemoryError` or system freezes

**Solution**:
1. Reduce buffer sizes:
   - Smaller `dff_history`
   - Smaller `joint_history_sec`

2. Clear caches:
   ```python
   import gc
   gc.collect()
   ```

3. Use smaller data types where possible

## Session Issues

### Session Won't Start

**Symptom**: Preview closes immediately or won't start

**Solution**:
1. Check all required config parameters
2. Verify camera is providing frames
3. Ensure ROIs are within image bounds
4. Check for errors in terminal output

### Early Session Termination

**Symptom**: Session ends before all trials complete

**Solution**:
1. Check for `Esc` key press
2. Verify no Python errors
3. Check disk space for data recording

## Hardware Issues

### LEDs Not Lighting

**Symptom**: No LED response

**Solution**:
1. Check GPIO connections
2. Verify resistor values (330Ω recommended)
3. Test LED independently
4. Check GPIO numbering (Board vs BCM)

### Water Reward Not Dispensing

**Symptom**: No water delivery

**Solution**:
1. Check valve wiring
2. Verify Arduino communication:
   ```python
   board.digitalWrite(ledReward, "HIGH")
   ```
3. Check water level
4. Inspect valve for clogs

## Getting Help

If you continue to experience issues:

1. Check the [GitHub Issues](https://github.com/pankajkgupta/clopy/issues)
2. Review the paper methods section
3. Check your configuration against the examples
4. Verify all dependencies are compatible

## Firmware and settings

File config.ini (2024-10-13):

[configsection]
config = raspicambraintrials_1roi_delay

[sentech_dlclive]
dlc_model_path = /media/murphy/fast_storage/dlc-live-projects/DLC_optostim2_resnet_50_iteration-26_shuffle-1/
vid_source = SentechCameraStream
data_root = /media/murphy/fast_storage/data/
video_file = behavior_video.mp4
offline_video_file = GT33_20230711170306.mp4
resolution = 640, 320
framerate = 30
awb_mode = off
shutter_speed = 60000
iso = 800
joint_history_sec = 5
ppmm = 3.5
bregma = 108, 128
control_point = fl_l
start_center = 590,110
start_radius_mm = 4
target_center = 590,80
target_radius_mm = 6
speed_threshold = 20
audio = 1
n_tones = 18
start_freq = 1000
audio_delay = 0
reward_delay = 1
reward_threshold_mm = 5
adaptive_threshold = 0
spont_sess_duration = 2
total_trials = 10
max_trial_dur = 30
success_rest_dur = 10
fail_rest_dur = 10
initial_rest_dur = 30
session_type = normal_audio_normal_reward
summary_file = expt_dlclive_summary.csv
summary_header = mouse_id, session, data_path, start, end, duration, fps, n_tones, start_radius, target_radius, rewards, audio, session_type
start_roi = 590,110
target_roi = 590,80

[sentech_give_rewards]
vid_source = SentechCameraStream
data_root = /media/murphy/fast_storage/data/
video_file = behavior_video.mp4
offline_video_file = GT33_20230711170306.mp4
resolution = 640, 320
framerate = 60
awb_mode = off
ppmm = 3.4
audio = 0
total_trials = 1
max_trial_dur = 10
end_rest_dur = 30
start_rest_dur = 30
summary_file = expt_dlclive_summary.csv
summary_header = mouse_id, session, data_path, start, end, duration, fps, n_tones, start_radius, target_radius, rewards, audio, session_type

[raspicambrainstroke]
vid_source = PiCameraStream
data_root = /home/pi/
raw_image_file = image_stream.hdf5
resolution = 256, 256
framerate = 15
awb_mode = off
shutter_speed = 600000
iso = 800
sensor_mode_v1 = 5
sensor_mode = 7
dff_history = 6
dff_range = -0.05,0.05
ppmm = 32
bregma = 108, 128
seeds_mm = {"ALM": {"ML": 1.5, "AP": 2.5},   "M1": {"ML": 1.8603, "AP": 0.64181},    "M2": {"ML": 0.87002, "AP": 1.4205},    "M1FL_1": {"ML": 2.2, "AP": -0.4},     "FL": {"ML": 2.4526, "AP": -0.5668},     "CFL": {"ML": 1.5, "AP": 0.25},     "RFL": {"ML": 1.25, "AP": 2.0},     "HL": {"ML": 1.6942, "AP": -1.1457},     "UN": {"ML": 2.7979, "AP": -0.97112},     "BC": {"ML": 3.4569, "AP": -1.727},     "TR": {"ML": 1.8644, "AP": -2.0204},     "RL": {"ML": 3.1712, "AP": -2.849},     "A": {"ML": 2.2932, "AP": -2.4962}, "AM": {"ML": 1.6479, "AP": -2.696}, "PM": {"ML": 1.6217, "AP": -3.6247}, "V1": {"ML": 2.5168, "AP": -3.7678}, "RS": {"ML": 0.62043, "AP": -2.8858}, "ANT": {"ML":0, "AP":3.525}, "LAMBDA": {"ML":0, "AP":-3.9}, "STROKE": {"ML":1.5, "AP":0.5}}
roi_operation = STROKE_L
roi_size = 0.3,0.3
audio = 1
n_tones = 10
reward_threshold = 0.052000000000000005
adaptive_threshold = 0
spont_sess_duration = 600
total_trials = 10
trial_duration = 120
rest_duration = 30
summary_file = expt_2roi_trial_summary.csv
summary_header = mouse_id, session, data_path, start, end, duration, fps, dff_history, n_tones, reward_threshold, rewards, audio, session_type

[raspicambrain_reward_punish_2roi]
vid_source = PiCameraStream
vid_root = /media/pi/WDEX4/google_drive/guptapg@tcd.ie/closedloop_fluorescence_data/2ROI/DU2/20190813163441/S1
data_root = /media/pi/data/cl_brain/
raw_image_file = image_stream.hdf5
resolution = 256, 256
framerate = 15
awb_mode = off
shutter_speed = 60000
iso = 800
sensor_mode = 7
dff_history = 6
ppmm = 25.6
bregma = 135, 128
seeds_mm = {"ALM": {"ML": 1.5, "AP": 2.5},   "M1": {"ML": 1.8603, "AP": 0.64181},    "M2": {"ML": 0.87002, "AP": 1.4205},    "M1FL_1": {"ML": 2.2, "AP": -0.4},     "FL": {"ML": 2.4526, "AP": -0.5668},     "CFL": {"ML": 1.5, "AP": 0.25},     "RFL": {"ML": 1.25, "AP": 2.0},     "HL": {"ML": 1.6942, "AP": -1.1457},     "UN": {"ML": 2.7979, "AP": -0.97112},     "BC": {"ML": 3.4569, "AP": -1.727},     "TR": {"ML": 1.8644, "AP": -2.0204},     "RL": {"ML": 3.1712, "AP": -2.849},     "A": {"ML": 2.2932, "AP": -2.4962}, "AM": {"ML": 1.6479, "AP": -2.696}, "PM": {"ML": 1.6217, "AP": -3.6247}, "V1": {"ML": 2.5168, "AP": -3.7678}, "RS": {"ML": 0.62043, "AP": -2.8858}, "ANT": {"ML":0, "AP":3.525}, "LAMBDA": {"ML":0, "AP":-3.9}, "STROKE": {"ML":1.5, "AP":0.5}}
roi_operation = BC_L-BC_R
roi_size = 0.3,0.3
audio = 1
n_tones = 18
audio_delay = 0
reward_delay = 1
reward_threshold = 0.1
adaptive_threshold = 0
spont_sess_duration = 2
total_trials = 60
max_trial_dur = 30
success_rest_dur = 5
fail_rest_dur = 10
initial_rest_dur = 30
summary_file = expt_2roi_trial_summary.csv
summary_header = mouse_id, session, data_path, start, end, duration, fps, dff_history, n_tones, reward_threshold, rewards, audio, session_type
bc_l = 35,175,8,8
bc_r = 212,175,8,8
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

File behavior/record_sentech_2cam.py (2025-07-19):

#########################
##### Pankaj Gupta#######
# Record behavior video from two sentech cameras at the same time.

import os
import sys
sys.path.append('..')
sys.path.append(os.getcwd())
from CameraFactory import CameraFactory
from imutils.video import FPS
import numpy as np
import math
import cv2
import imutils
import time
from datetime import datetime
from threading import *
import RPi.GPIO as GPIO
from Arduino import Arduino
import cvui
import tables
import roi_manager
from collections import deque
import re
import json
from configparser import ConfigParser
import csv
import helper as clh
# import board
# import busio
# import adafruit_mpr121
from audiostream import get_output
from audiostream.sources.wave import SineSource
import warnings
import random as rm
import itertools

warnings.filterwarnings("ignore", category=DeprecationWarning)

configPath = '../config.ini'
config      = ConfigParser()
config.read(configPath)
cfg = 'sentech_give_rewards'
cfgDict = dict(config.items(cfg))
vidSourceName = cfgDict['vid_source']
data_root   = cfgDict['data_root']
image_stream_filename = cfgDict['video_file']
res     = list(map(int, cfgDict['resolution'].split(', ')))
fr = int(cfgDict['framerate'])
audio = float(cfgDict['audio'])
total_trials = int(cfgDict['total_trials'])
maxTrialDur = int(cfgDict['max_trial_dur'])
startrest_duration = int(cfgDict['start_rest_dur'])
endrest_duration = int(cfgDict['end_rest_dur'])
n_tones = 0
audiodelay = 0
sessionType = clh.SessionType.behavior_recording

#list of sessions. session_name,reward_threshold_mm
sessions = [('S1',0)]

pinBrainTTL = 13
ledFailTrial = 12
ledReward = 7
ledLightTTL = 40
# board = Arduino("115200", port="/dev/ttyACM0") # plugged in via USB, serial com at rate 115200
# board.pinMode(pinBrainTTL, "OUTPUT")
# board.pinMode(ledReward, "OUTPUT")
# board.pinMode(ledFailTrial, "OUTPUT")
# board.pinMode(ledLightTTL, "OUTPUT")

GPIO.setmode (GPIO.BOARD)
GPIO.setup(pinBrainTTL,GPIO.OUT, initial=GPIO.LOW)
GPIO.setup(ledReward,GPIO.OUT, initial=GPIO.LOW)
GPIO.setup(ledFailTrial,GPIO.OUT, initial=GPIO.LOW)
GPIO.setup(ledLightTTL,GPIO.OUT, initial=GPIO.LOW)

ts_trigger = 0
ts_detection = 0
run_threads = True
runPreview = True
runRecording = True

mouse_id = input("Please enter mouse ID: ")

WINDOW_NAME = 'Closed loop'

cvui.init(WINDOW_NAME)
cvui.init(WINDOW_NAME + '2')

#blink 'led' once for 't' length
def timed_led(led, t):
    global fr, run_threads
    GPIO.output(led, GPIO.HIGH)
    while run_threads:
        time.sleep(1/fr)
    GPIO.output(led, GPIO.LOW)

def blink_led(led, t):
    GPIO.output(led, GPIO.HIGH)
    time.sleep(t)
    GPIO.output(led, GPIO.LOW)
def blink_led_arduino(led, t):
    board.digitalWrite(led, "HIGH")
    # board.analogWrite(led, 180)
    time.sleep(t)
    board.digitalWrite(led, "LOW")
    # board.analogWrite(led, 0)

#continuously blink 'led' for 't' length and 'gap' between blinks
def cont_blink_led(led, t, gap):
    print("blink led continuous")
    global ts_trigger
    global run_threads
    while(run_threads):
        ts_trigger = time.time()
        blink_led(led,t)
        time.sleep(gap)
        
summary_filename    = data_root + os.sep + config.get(cfg, 'summary_file')
summary_exists      = os.path.isfile(summary_filename)
summaryfile         = open (summary_filename, 'a', encoding="utf-8")
headers             = [col.strip() for col in config.get(cfg, 'summary_header').split(',')]
writer              = csv.DictWriter(summaryfile, delimiter=',', lineterminator='\n',fieldnames=headers)
if not summary_exists:
    writer.writeheader()  # file doesn't exist yet, write a header

print("Start preview\n\n")
# initialize the camera and grab a reference to the raw camera capture
exec('from ' + vidSourceName + ' import ' + vidSourceName)
# initialize the camera and grab a reference to the raw camera capture
deviceIdx = 0
vs1 = CameraFactory(eval(vidSourceName+'(cfgDict, deviceIdx).start()'))
image1 = vs1.get_image()
deviceIdx = 1
vs2 = CameraFactory(eval(vidSourceName+'(cfgDict, deviceIdx).start()'))
image2 = vs2.get_image()

GPIO.output(ledLightTTL, GPIO.HIGH)
last_time=time.time()
while runPreview:
    start = time.time()
    #image = frame.array
    image1 = vs1.get_image()
    if image1 is None:
        print('Image1 none')
        continue
    image1 = image1[-res[1]:, -res[0]:, :]

    image2 = vs2.get_image()
    if image2 is None:
        print('Image2 none')
        continue
    image2 = image2[-res[1]:, -res[0]:, :]

    cvui.imshow(WINDOW_NAME, cv2.resize(image1,(image1.shape[1]*2,image1.shape[0]*2)))
    cvui.imshow(WINDOW_NAME + '2', cv2.resize(image2,(image2.shape[1]*2,image2.shape[0]*2)))
    
    # Press Esc or Ctrl-C to stop the program
    k = cv2.waitKey(1)
    if k == 27:
        runPreview = False
        break
    
    print('FPS', round(1 / (time.time() - last_time), 2), end='\r')
    last_time = time.time()
    # time.sleep(max(1./fr - (time.time() - start), 0))

#co save the configuration used in current directory
with open(configPath, 'w', encoding="utf-8") as f:
        config.write(f)

GPIO.output(ledLightTTL, GPIO.LOW)

tr = 0
# Get the current time and initialize the project folder
tm = datetime.now()
data_name = str(tm.year) + \
            format(tm.month, '02d') + \
            format(tm.day, '02d') + \
            format(tm.hour, '02d') + \
            format(tm.minute, '02d') + \
            format(tm.second, '02d')
data_root = data_root + os.sep + mouse_id + os.sep + data_name

if not os.path.exists(data_root):
        print("Creating data directory: ",data_root)
        os.makedirs(data_root)
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

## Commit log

2024-10-08 added VideoStream class to stream from a video file instead of a camera
2024-10-22 added clmf analysis scripts and some processed data to plot
    [clmf_kld_df.csv, clmf_sessions_df.csv]
2024-10-22 renamed data directory to processed_data
    [clmf_kld_df.csv, clmf_sessions_df.csv]
2024-10-22 added processed data for clnf script to plot
    [clnf_sessions_df.csv]
2024-10-24 fix errors while running scripts
    [helper.py]
2024-10-31 added parts list and assembly instructions
2024-11-13 added model files for 3D printed components
    [MirrorHolderFront.dxf, MirrorHolderRear.dxf, MouseEnclosureTop.dxf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]
2025-06-02 modified the sentech class to allow multiple cameras
2025-06-04 added script to record behavior from two sentech cameras simultaneously
2025-07-19 added script to record 2 sentech cameras simultaneously
2026-01-01 switched fig1 and fig2
